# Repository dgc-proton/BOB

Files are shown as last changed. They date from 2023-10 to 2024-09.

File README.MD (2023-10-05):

#B.O.B. - Barely Operational Bot

Code - Robot Code
Model - CAD model
Design - Design/Idea files

## Git Guidelines

- don’t force any command without approval of everyone else
- don’t use advanced features that mess with file histories (though amend is ok when used properly)
- give descriptive commit messages
- keep commits small & often when possible (or when we remember!)
- use branches & merge changes form origin/main into the branch regularly

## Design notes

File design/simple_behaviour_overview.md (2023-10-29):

# B.O.B. Behaviour Overview

```mermaid
stateDiagram-v2

    state "Startup Health Check" as health_check
    state "Check for Opponent" as check
    state "Turn Towards Opponent\n(sensor distance min.)" as attack
    state "Check for Lines" as line_detect
    state "Steer Away from Line(s)" as line_avoid
    state "Maximum Power to Motors!" as steer_power
    state "Low Power to Motors" as go_slow
    state "Turn in One Direction" as turn_to_find

    [*] --> health_check: Power On
    health_check --> line_detect: Button Pressed
    line_detect --> check: No Line Detected
    line_detect --> line_avoid: Line Detected
    line_avoid --> line_detect
    check --> attack: Opponent Detected
    attack --> steer_power
    steer_power --> line_detect
    check --> go_slow: No Opponent Detected
    go_slow --> turn_to_find
    turn_to_find --> line_detect
```

# Navigation

### Inputs

* line sensors (IR x 2)
* object sensors (ultrasonic x 4)

### Map

Not used in the simple behaviour model.

### Path

Not used in the simple behaviour model.

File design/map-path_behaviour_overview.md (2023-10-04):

# B.O.B. Behaviour Overview

```mermaid
stateDiagram-v2

    state "Startup Health Check" as health_check
    note left of line_detect: An alternative would be to\nuse an Interupt Service\nRoutine for line detection
    state "Check for Opponent" as check
    state "Update Map & Path:\nDrive at Opponent /\nSearch Pattern" as attack
    state "Check for Lines" as line_detect
    state "Update Map & Path:\nAvoid Line (top priority)" as line_avoid
    state "Update Steering &\nAdjust Motor Power" as steering
    state "Update Steering &\nAdjust Motor Power" as steer_power

    [*] --> health_check: Power On
    health_check --> line_detect: Button Pressed
    line_detect --> check: No Line
    line_detect --> line_avoid: Line Detected
    line_avoid --> steering
    steering --> check
    check --> attack
    attack --> steer_power
    steer_power --> line_detect
```

# Navigation

### Inputs

* wheel encoders using ISR
* line sensors (IR x 4)
* object sensors (ultrasonic x ?)

### Map

Array that tracks the location of the bot, opponent (or last known location of opponent) and lines. As time passes localization gets less accurate, so should we remove or de-value data as it gets older? The location of the bot can be tracked by array indices giving the cell that the centre of the robot is in, and a unit vector for the direction it is facing.

Information on where the various sensors are (for object and line detection) located in relation to the centre of the bot will be needed to accurately update the map with the location of lines & opponent distance.

### Path

Algorithm that decides which way the bot should be facing and the speed that it should be going at, based on avoiding lines (highest priority) and finding or attacking the opponent.

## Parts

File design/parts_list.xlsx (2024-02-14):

Parts | Quantity | Links | Cost | Mass (g) | Total Mass
Hailege ESP32 ESP-32S ESP-WROOM-32 | 1 | N.A. | Given | 10 | 10
HC-SR04 Ultrasonic Sensor | 2 | N.A. | Given | 9 | 18
Battery | 1 | N.A. | Given | 200 | 200
Motor driver L298N | 1 | N.A. | Given | 33 | 33
N20 DC GEARED MOTOR | 2 | N.A. | Given | 10 | 20
43MM N20 | 2 | N.A. | Given | 19 | 38
QTR-1A Infrared | 2 | N.A. | Given | 0.2 | 0.4
Mass of Shell | 1 | N.A. | Estimated | 139.03 | 139.03
 |  |  |  |  | 458.43 | Sum
 |  |  |  |  | 41.57 | Remainder

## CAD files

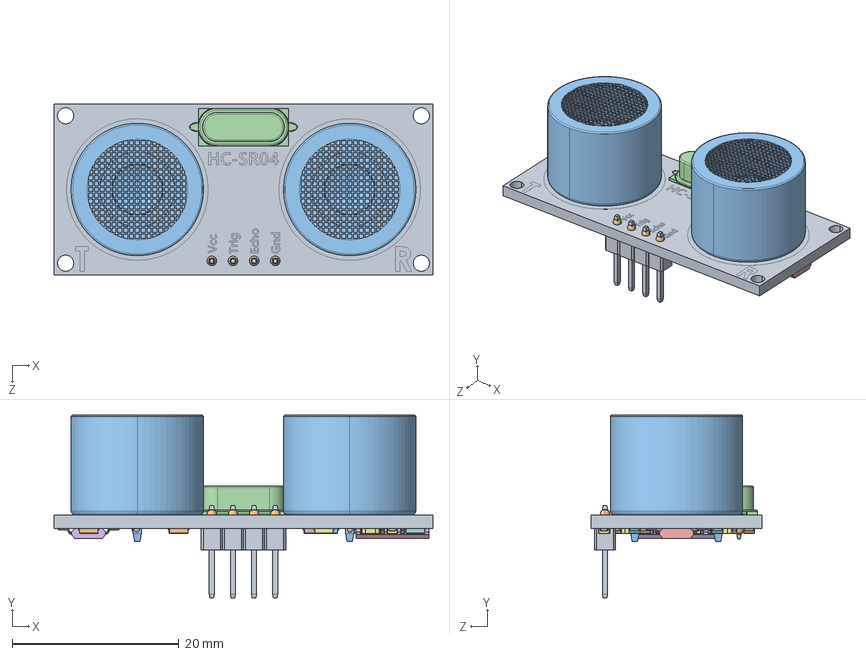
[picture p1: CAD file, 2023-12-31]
model/components/HC-SR04.SLDASM
45.5 x 22.0 x 20.5 mm
HC-SR04board.STEP
solder.STEP x 10
Emitter.STEP x 2
CrystalOscillator.STEP
smdChip14pin.STEP x 2
smdChip16pin.STEP
smdceramiccapacitor.STEP x 7
smdResistor753.STEP x 3
smdResistor392.STEP
smdResistor103.STEP x 6
smdResistor124.STEP x 2
smdResistor335.STEP
smdResistor102.STEP
smdResistor563.STEP
smdResistor622.STEP
smdResistor412.STEP
headerMale.STEP x 4

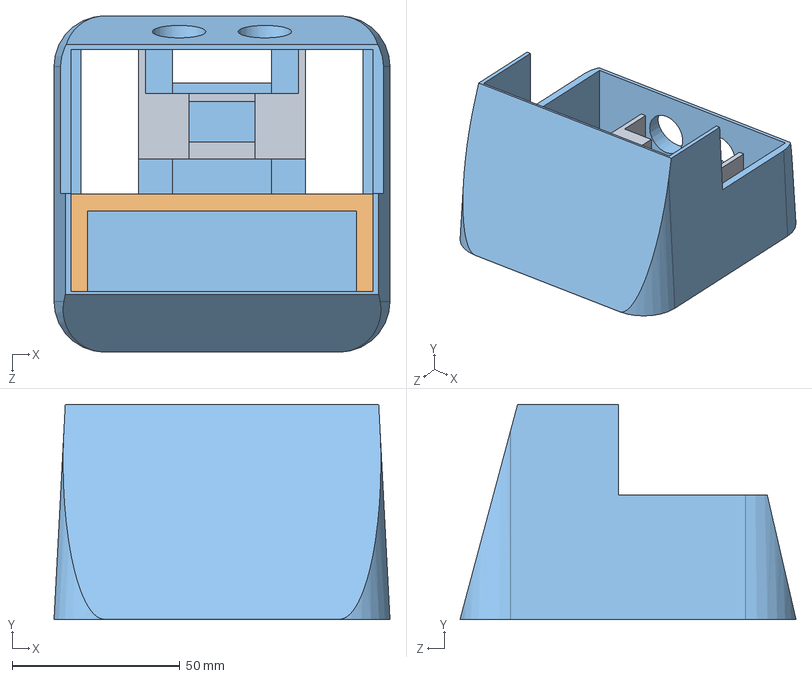
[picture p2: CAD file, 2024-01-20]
model/shell subparts/shell_assembly_test.SLDASM
100.0 x 64.0 x 100.0 mm
shell-part1
shell-part2
shell-part3

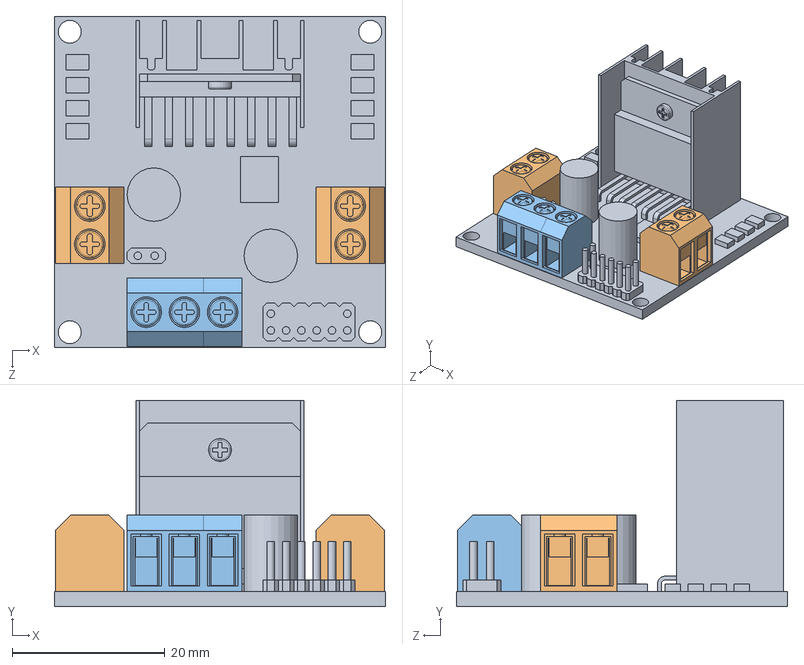
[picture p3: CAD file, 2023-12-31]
model/components/L298N.SLDASM
43.3 x 27.0 x 43.3 mm
Pcb
Pengunci x 2
Pengunci 2

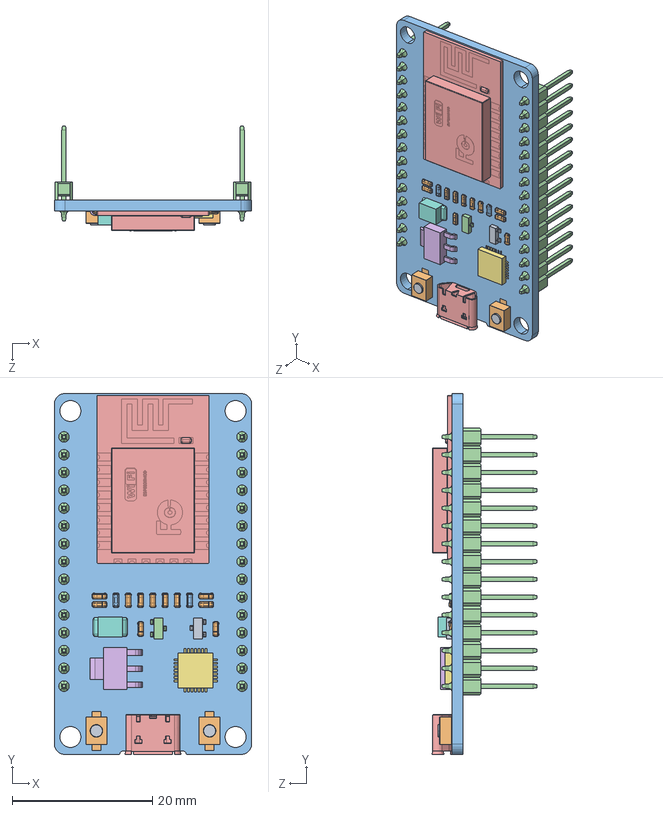
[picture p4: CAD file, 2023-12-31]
model/components/esp32_dev_kit_v1_asm.SLDASM
28.1 x 51.5 x 15.0 mm
BUTTONFLASH-13_2.stp x 2
BUTTONFLASH-14_2.stp x 2
PCB.stp
PIN.stp x 30
WIFI_CARD_2.stp
RECTANGULARCHIP_2.stp
MICROCHIP_2.stp
TANCHIP_2.stp
TRANSISTOR_3-LEG_2.stp
RESISTOR1_2.stp x 11
RESISTOR2-32_2.stp x 2
TRANSISTOR_3-LEG2_2.stp
USB_SOCKET_2.stp

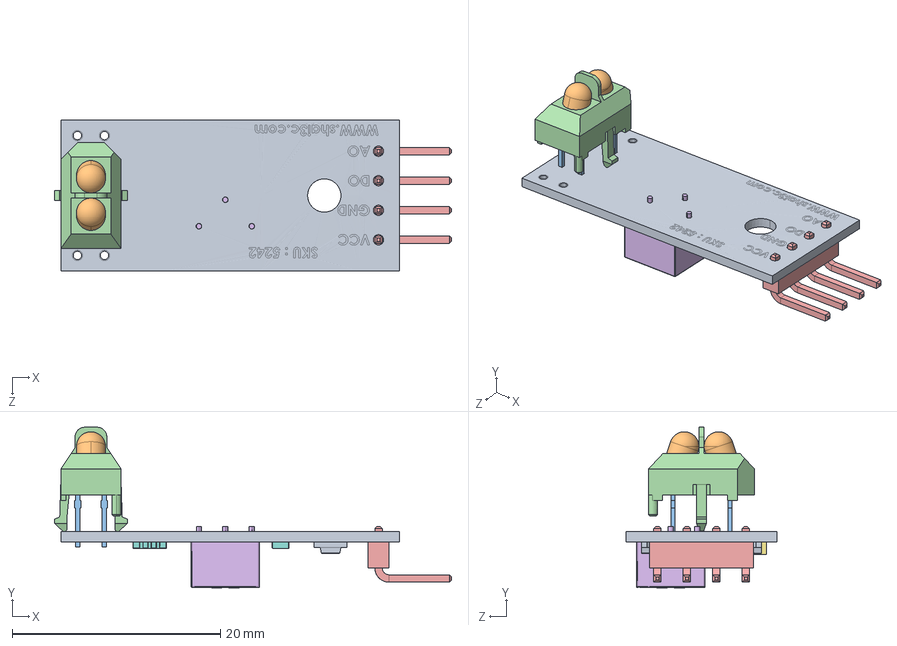
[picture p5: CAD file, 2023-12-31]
model/components/TCRT5000L Module.SLDASM
38.1 x 15.4 x 14.5 mm
Board.IGS
LEDs.IGS
Metal Contacts.IGS
TCRT50003.IGS
Pin Header.IGS
3362P-1-102LF-final.IGS
LM393 IC.IGS
103 SMD.IGS x 7
Surface Mount Chip LED 3.2x1.6mm 2.IGS x 2

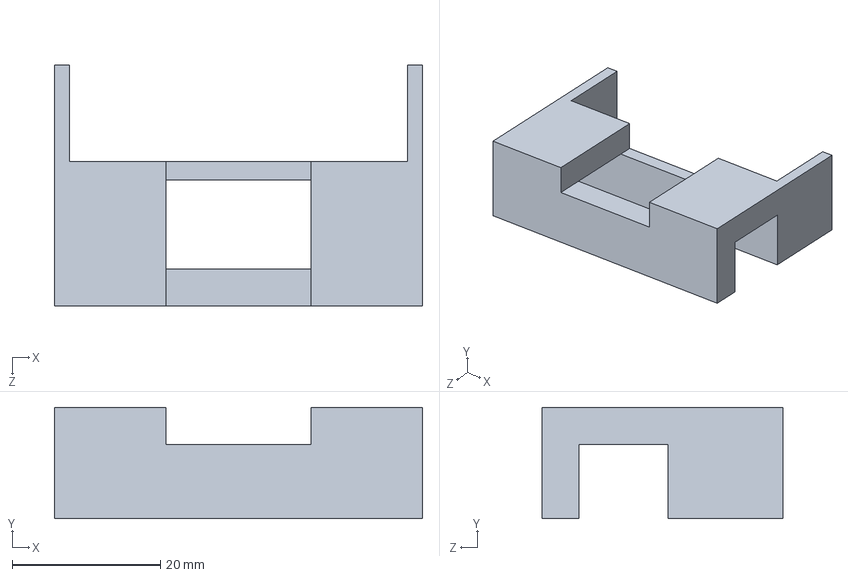
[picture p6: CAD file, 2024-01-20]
model/shell subparts/shell-part3.SLDPRT
49.6 x 15.0 x 32.5 mm

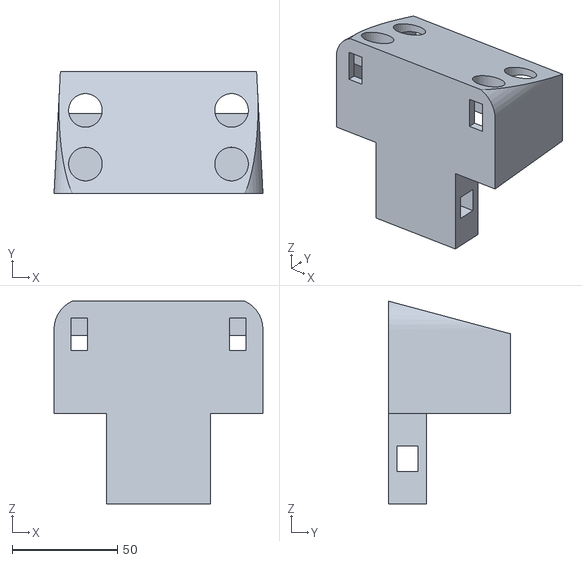
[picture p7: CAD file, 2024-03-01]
model/Shell-Print.STL
99.4 x 58.0 x 96.4

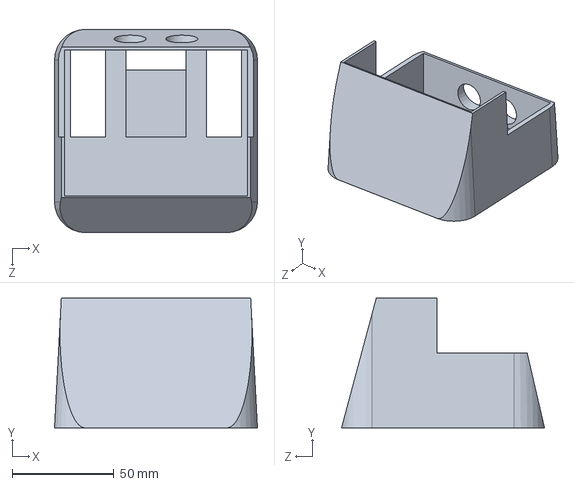
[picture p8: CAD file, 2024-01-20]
model/shell subparts/shell-part1.SLDPRT
100.0 x 64.0 x 100.0 mm

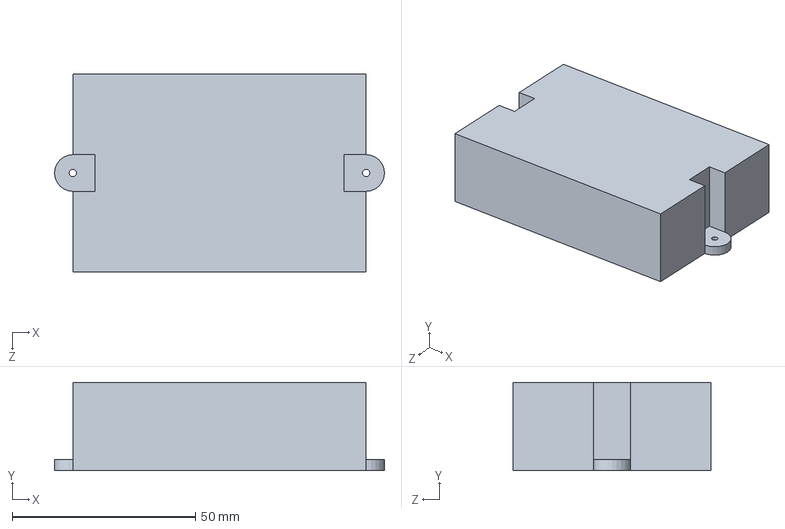
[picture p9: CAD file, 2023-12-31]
model/components/battery.SLDPRT
90.0 x 24.0 x 54.0 mm

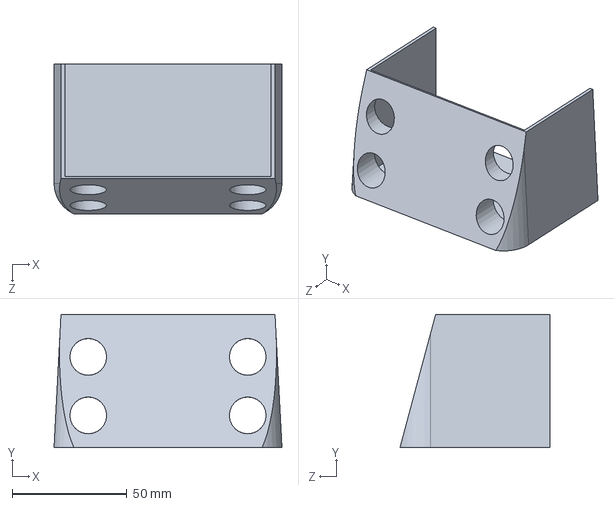
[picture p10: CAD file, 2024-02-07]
model/front.SLDPRT
99.4 x 58.0 x 65.4 mm

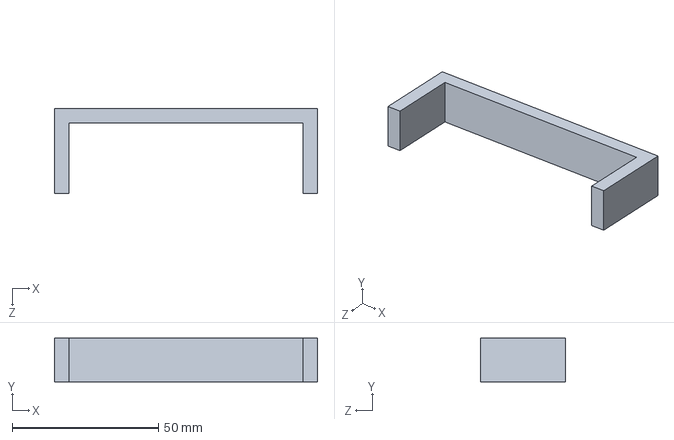
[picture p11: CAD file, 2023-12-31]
model/shell subparts/shell-part2.SLDPRT
90.0 x 15.0 x 29.0 mm

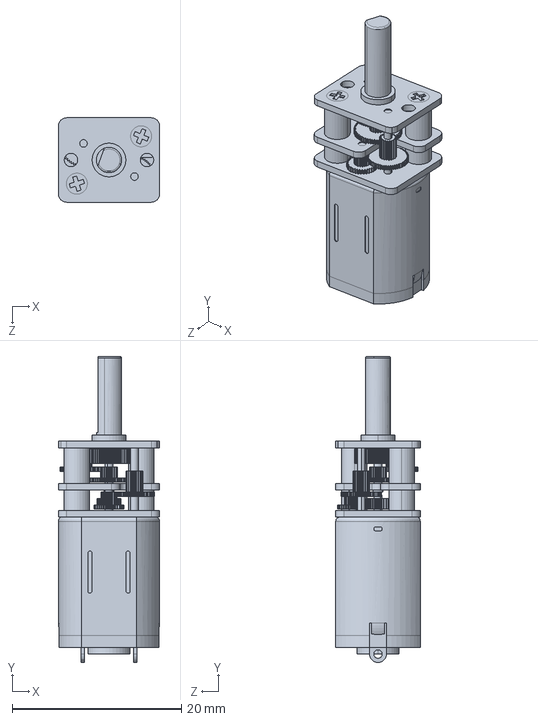
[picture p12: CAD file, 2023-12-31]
model/components/N20 DC MOTOR.step.SLDPRT
12.0 x 36.2 x 10.0 mm

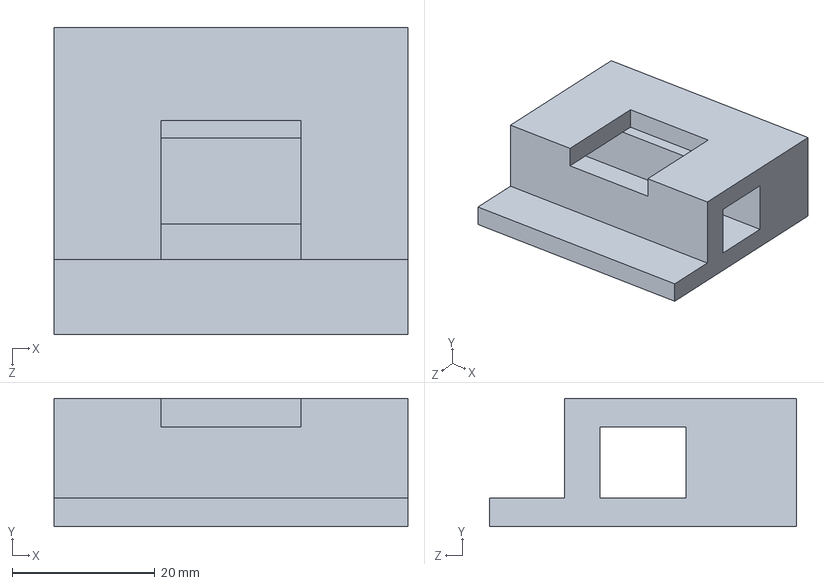
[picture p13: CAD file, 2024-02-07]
model/wheelbase.SLDPRT
49.6 x 18.0 x 43.0 mm

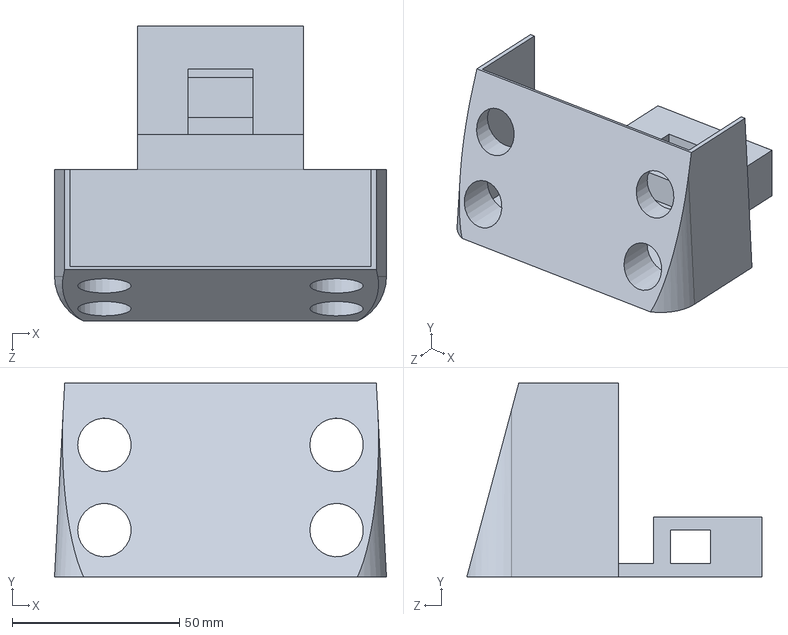
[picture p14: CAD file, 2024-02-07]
model/shell-bottomV3.SLDPRT
99.4 x 58.0 x 88.4 mm

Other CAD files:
model/components/QRE1113.SLDASM
model/BOB_assemblyV3.SLDASM
model/ShellV5.SLDPRT
model/components/Pengunci 2.SLDPRT
model/BOB_Assembly.SLDASM
model/Shell.SLDPRT
model/components/Pcb.SLDPRT
model/components/Pengunci.SLDPRT
model/components/QRE1113.SLDPRT
model/components/wheel.SLDPRT
model/old parts/BOB_assembly.SLDASM
model/old parts/BOB_assemblyV1.SLDASM
model/old parts/BOB_assemblyV2.SLDASM
model/old parts/Cut-Extrude2[1].SLDPRT
model/old parts/Cut-Extrude2[2].SLDPRT
model/old parts/Shell-assembly.SLDASM
model/old parts/sheelV4.SLDPRT
model/old parts/shell-bottom.SLDPRT
model/old parts/shell-bottomV2.SLDPRT
model/old parts/shell-topV2.SLDPRT
model/old parts/shell-topV3.SLDPRT
model/old parts/shell.SLDPRT
model/old parts/shellV2.SLDPRT
model/old parts/topV2_assembly.SLDASM
model/shell-bottom.SLDPRT
model/shell-bottomV2.SLDPRT
model/shell-top.SLDPRT
model/shell-topV2.SLDPRT
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

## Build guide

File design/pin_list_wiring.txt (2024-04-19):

Colour coding:
The bundle of four cables go diagonally across, so the ones sticking out the right are for the sensors on the left and vice-versa.
Red: 5V (apart from single wire from battery to H-Bridge which is 12V)
Black: ground (-ve battery terminal)
Yellow, bundle of 4: object sensors echo
Blue, bundle of 4: object sensors trigger
Green, bundle of 4: line sensors Vcc
White, bundle of 4: line sensors out
Bundle of 6, one of each colour: these are from the H-Bridge to the MCU so are fully visible

===================================================================================
FIXES REQUIRED
Common Pins:
GND H-Bridge: Ultrasonic Grounds, Line Sensor Grounds, Arduino Ground
5V H-Bridge: Ultrasonic Power, ESP32 VIN
Fixes:
Pin Soldering on Ultrasonics, Add ESP32 VIN to crimped connection

Battery Pins:
1. Power --> +12
2. Ground --> GND

H-Bridge
ENA --> 13
In1 --> 12
In2 --> 14

ENB --> 15
In3 --> 2
In4 --> 4

Line Sensors
Left Power --> 26
Left Out --> 27
Right Power --> 33
Right Out --> 25

Obj Sensors
Left Trigger --> 16
Left Echo --> 17
Right Trigger --> 5
Right Echo --> 18

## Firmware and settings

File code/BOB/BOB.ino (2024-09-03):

/*
**************************************
**  B.O.B. - Barely Operational Bot  **
**************************************
*
* Authors:
* Dave Riley
* Raghav Kejriwal
* Loïc Zammit
* 
* Code guidelines:
* 	- variable names should be all lowercase using underscores, struct or class names CamelCase, global variables prefixed with g_
* 	- use spaces around operators, apart from in arguments
* 	- first open brace { on same line, closing brace } a line by itself
* 	- keep things simple and readable
* 
* NB: With our board, may have to hold 'BOOT' Switch when uploading sketch
*
* ERROR CODES BUILTIN LED: (REPEAT ERROR CODES 10 TIMES IN 2 SEC INTERVALS (?))
* 1: . . . . . : Issue with update_motor, g_motor_commands has conflicting/erroneous values. Either turn is not within [-1, 1] or direction says reverse, but turn is not set to straight (0) {while this is possible to implement, it is rather confusing}. Hopefully code logic should never bring such a situation.
*/

/**********
Definitions
***********/

// left motor
#define LMOTOR_PWM_PIN   13
#define LMOTOR_DIR_PIN_1 12  // swapped the pin definitions around because motors were running in reverese
#define LMOTOR_DIR_PIN_2 14
const float LMOTOR_CORRECTION_FACTOR = 1; // must be <=1
const float LMOTOR_TURN_CORRECTION_FACTOR = 0.4; // motors slower in reverse

#if LMOTOR_CORRECTION_FACTOR > 1
	#error Motor correction factors must be less than or equal to 1
#endif

// right motor
#define RMOTOR_PWM_PIN   15
#define RMOTOR_DIR_PIN_2 32  // swapped the pin definitions around because motors were running in reverese
#define RMOTOR_DIR_PIN_1 4
const float RMOTOR_CORRECTION_FACTOR = 1; // must be <=1
const float RMOTOR_TURN_CORRECTION_FACTOR = 0.4; // motors slower in reverse

#if RMOTOR_CORRECTION_FACTOR > 1
	#error Motor correction factors must be less than or equal to 1
#endif

// both motors
#define MOTORMIN 60  // to account for deadband of motors, set based on motor with largest deadband
#define TURNING_FACTOR_FAST 50  // amount of PWM to decrease the turning wheel by when driving quickly

// IR line sensors
#define LINE_LEFT_PIN 27
#define LINE_LEFT_POWER_PIN 26
#define LINE_RIGHT_PIN 25
#define LINE_RIGHT_POWER_PIN 33
#define LINE_LEFT_THRESHOLD 1000  // based on manual callibration
#define LINE_RIGHT_THRESHOLD 1000  // based on manual callibration

//Object sensors
#define RING_SIZE 600

#define LOBJSENSOR_TRIG 16
#define LOBJSENSOR_ECHO 17

#define ROBJSENSOR_TRIG 5
#define ROBJSENSOR_ECHO 18

// Built-in LED
#define LED_BUILTIN 2

// START BUTTON
#define START_BUTTON 19

/***************
Global Variables
****************/

//Stores readings from the ultrasonic and infrared sensors
struct Sensors {
	float object_left = 4000.0;
	float object_right = 4000.0;
	float last_seen_right = true;
	bool line_left = false;
	bool line_right = false;
} g_sensor_readings;  // the structure name

// stores commands for motor power and steering
struct MotorCommands {
	int turn = 0; // -1 for left; 1 for right; 0 for straight.
	bool forward = true; // true for forward, false for reverse. Can only be in reverse if turn is set to 0, or straight! Not allowing a reverse turning possibility, since doing an on the spot turn anyways.
	int motor_power;
} g_motor_commands;  // the structure name

/******************
Function Prototypes
*******************/
void line_check(void);
void reverse_escape(void);
void single_side_escape(void);
void search_attack(void);
void update_object_sensors(void);
void update_motor(void);
void turn_left(void);
void turn_right(void);
void dir_forward(void);
void dir_reverse(void);

/*********
Setup Code
**********/
void setup() {
    Serial.begin(115200); //Starts serial output
    analogWrite(LMOTOR_PWM_PIN, 0);
    analogWrite(RMOTOR_PWM_PIN, 0);
	//Set built-in LED pin (D13) as output & switch on to show that setup in progress
	pinMode(LED_BUILTIN, OUTPUT);
	digitalWrite(LED_BUILTIN, HIGH);

	//Set motors pin modes
	pinMode(LMOTOR_DIR_PIN_1, OUTPUT);
	pinMode(LMOTOR_DIR_PIN_2, OUTPUT);
	pinMode(LMOTOR_PWM_PIN, OUTPUT); 
	pinMode(RMOTOR_DIR_PIN_1, OUTPUT);
	pinMode(RMOTOR_DIR_PIN_2, OUTPUT);
	pinMode(RMOTOR_PWM_PIN, OUTPUT);
	
	//Set ultrasonic sensor pin modes
	pinMode(LOBJSENSOR_TRIG, OUTPUT);
	pinMode(LOBJSENSOR_ECHO, INPUT);
	pinMode(ROBJSENSOR_TRIG, OUTPUT);
	pinMode(ROBJSENSOR_ECHO, INPUT);

	//Set line sensors pin mode
	pinMode(LINE_LEFT_POWER_PIN, OUTPUT);
	pinMode(LINE_RIGHT_POWER_PIN, OUTPUT);
	pinMode(LINE_LEFT_PIN, INPUT);
	pinMode(LINE_RIGHT_PIN, INPUT);

    // Start Button
    pinMode(START_BUTTON, INPUT_PULLUP);

	//Power on to the line sensors
	digitalWrite(LINE_LEFT_POWER_PIN, HIGH);
	digitalWrite(LINE_RIGHT_POWER_PIN, HIGH);

	//Set motors in forward direction
	dir_forward();

    for (int i=0; i<5; i++) {
        update_object_sensors();
    }

	//Blinks LED to show setup completed sucessfully
	for(int i=0; i<3; i++) {
		digitalWrite(LED_BUILTIN, LOW);
		delay(500);
		digitalWrite(LED_BUILTIN, HIGH);
		delay(500);
		digitalWrite(LED_BUILTIN, LOW);
	}

    while(true) {
        bool start_check = digitalRead(START_BUTTON);
        if (start_check == false) {
            break;
        }
    }

    g_motor_commands.motor_power = 80;
    update_motor();
    delay(400);
    g_motor_commands.motor_power = 0;
    update_motor();
}


/********
Main Code
*********/

void loop() { //Main Control loop	
	line_check(); //Checks for lines
    //update_object_sensors(); //debugging
	 //Bound detection
	if(g_sensor_readings.line_left && g_sensor_readings.line_right) {
    //If both lines detected in the front, reverse	
        //Serial.println("Reverse Escape");
		reverse_escape();
	} else if(g_sensor_readings.line_left) {
    //If one line detected in the left, turn right
        //Serial.println("Turning Right");
        left_side_escape();
	} else if(g_sensor_readings.line_right) {
    //If one line detected on the right, turn left
        //Serial.println("Turning Left");
        right_side_escape();
	} else {
    //If no bounds detected, search for opponent
		update_object_sensors();
        //Serial.println("Search Attack");
		search_attack();
	}

  // debugging
  
  /*Serial.print("object left: ");
  Serial.println(g_sensor_readings.object_left);
  Serial.print("object right: ");
  Serial.println(g_sensor_readings.object_right);
  Serial.print("last seen right?: ");
  Serial.println(g_sensor_readings.last_seen_right);
  Serial.print("line left: ");
  Serial.println(g_sensor_readings.line_left);
  Serial.print("line right: ");
  Serial.println(g_sensor_readings.line_right);
  Serial.print("turn (-1 left, 0 straight, 1 right): ");
  Serial.println(g_motor_commands.turn);
  Serial.print("forward? ");
  Serial.println(g_motor_commands.forward);
  Serial.print("motor power: ");
  Serial.println(g_motor_commands.motor_power);
  Serial.println();
  delay(5000);*/
  
}


void line_check() { 
    //Update values for lines sensed from the QRE1113 **DIGITAL** breakout board sensors 
  //Lower numbers mean more refleacive, more than 3000 means nothing was reflected
  //(testing on black tape and white masking tape suggest anything below 150 is a white line)
  if (min(g_sensor_readings.object_left,g_sensor_readings.object_right) < 100) {
    return;
  }
  pinMode(LINE_LEFT_PIN, OUTPUT);
  digitalWrite(LINE_LEFT_PIN, HIGH);  
  delayMicroseconds(10);
  pinMode(LINE_LEFT_PIN, INPUT);
  long time = micros();
  //time how long the input is HIGH, but quit after 3ms as nothing happens after that
  while (digitalRead(LINE_LEFT_PIN) == HIGH && micros() - time < 3000);
  int diff = micros() - time;
  Serial.print("Left:");
  Serial.println(diff);
	if(diff < LINE_LEFT_THRESHOLD){
		g_sensor_readings.line_left = true;
	} else {
		g_sensor_readings.line_left = false;
	}

  pinMode(LINE_RIGHT_PIN, OUTPUT);
  digitalWrite(LINE_RIGHT_PIN, HIGH);  
  delayMicroseconds(10);
  pinMode(LINE_RIGHT_PIN, INPUT);
  time = micros();
  //time how long the input is HIGH, but quit after 3ms as nothing happens after that
  while (digitalRead(LINE_RIGHT_PIN) == HIGH && micros() - time < 3000);
  diff = micros() - time;
  Serial.print("Right:");
  Serial.println(diff);
	if(diff < LINE_RIGHT_THRESHOLD){
		g_sensor_readings.line_right = true;
	} else {
	        g_sensor_readings.line_left = false;
        }
}

void update_object_sensors() {
	// Updates the global struct with readings from the object sensors. If sight of
	// the enemy is lost, also updates the history of direction enemy was last seen in

	// Ultrasonics output HIGH pulse for the amount of time it takes the waves to reflect back
	// pulseIn measures that, and distance in mm is then calculated
	
	//Left utrasonic sensor
    digitalWrite(LOBJSENSOR_TRIG, LOW);
	delayMicroseconds(2);
	digitalWrite(LOBJSENSOR_TRIG, HIGH);
	delayMicroseconds(10);
	digitalWrite(LOBJSENSOR_TRIG, LOW);
	int Lduration = pulseIn(LOBJSENSOR_ECHO, HIGH);
	
    //Right ultrasonic sensor
	digitalWrite(ROBJSENSOR_TRIG, LOW);
	delayMicroseconds(2);
	digitalWrite(ROBJSENSOR_TRIG, HIGH);
	delayMicroseconds(10);
	digitalWrite(ROBJSENSOR_TRIG, LOW);
	int Rduration = pulseIn(ROBJSENSOR_ECHO, HIGH);
	
	float Ldistance = Lduration * 0.34/2;
	float Rdistance = Rduration * 0.34/2;
	
	// Updates history of direction enemy was last seen in
	if(min(Ldistance, Rdistance) > RING_SIZE && min(g_sensor_readings.object_left, g_sensor_readings.object_right) < RING_SIZE) {
		float left_right = g_sensor_readings.object_left - g_sensor_readings.object_right;
		if(left_right >= 0) {
			g_sensor_readings.last_seen_right = true;
		} else if(left_right < 0) {
			g_sensor_readings.last_seen_right = false;
		}
	}
	g_sensor_readings.object_left = Ldistance;
	g_sensor_readings.object_right = Rdistance;

	return;
}

void reverse_escape() {
	// does a quick reverse, a turn, then returns control of motor and steering to normal
	// sets motors to reverse direction, delays to make sure it gets somewhere before checking for next loop iteration. completes a line check and iteration of loop done if line check still returns positive
	do {
		g_motor_commands.motor_power = 255;
		dir_reverse();
		// revers set to high speed so can counter forward momentum if needed.
		delay(500);
		line_check();
	} while(g_sensor_readings.line_left && g_sensor_readings.line_right);
	if(g_sensor_readings.last_seen_right == true) {
		g_motor_commands.motor_power = 60;
		turn_right();
	} else {
		g_motor_commands.motor_power = 60;
		turn_left();
	}
	delay(200);
	g_motor_commands.motor_power = 0;
	dir_forward();
	return;
}

void left_side_escape() {
    do {
		g_motor_commands.motor_power = 100;
		dir_reverse();
		// revers set to high speed so can counter forward momentum if needed.
		delay(150);
		line_check();
	} while(g_sensor_readings.line_left && g_sensor_readings.line_right);
    g_motor_commands.motor_power = 60;
    turn_right();
    delay(200);
    return;
}

void right_side_escape() {
    do {
		g_motor_commands.motor_power = 100;
		dir_reverse();
		// revers set to high speed so can counter forward momentum if needed.
		delay(150);
		line_check();
	} while(g_sensor_readings.line_left && g_sensor_readings.line_right);
    g_motor_commands.motor_power = 60;
    turn_left();
    delay(200);
    return;
}


void search_attack() {// Searches for the opponent, if opponent found to be in range will accelerate full speed at them

	if(min(g_sensor_readings.object_left, g_sensor_readings.object_right) > RING_SIZE){
		// the enemy is not in range, turn in the direction they were last seen
		if(g_sensor_readings.last_seen_right){
			g_motor_commands.motor_power = 60;
			turn_right();
            delay(200);
            g_motor_commands.motor_power = 0;
            dir_forward();
            //Serial.println("Stopped");
            //delay(1000);
			return;
		}else{
			g_motor_commands.motor_power = 60;
			turn_left();
            delay(200);
            g_motor_commands.motor_power = 0;
            dir_forward();
            //Serial.println("Stopped");
            //delay(1000);
			return;
		}
	}

	// If we haven't returned to the caller yet then the enemy is in range
	float left_minus_right = g_sensor_readings.object_left - g_sensor_readings.object_right;
	if(abs(left_minus_right) < 100){
		// If the enemy is pretty much in front of us, CHARGE!
		g_motor_commands.motor_power = 255;
		dir_forward();
		return;
	}

	// If we haven't charged then we need to turn to face the enemy better
	if(left_minus_right > 100){
		g_motor_commands.motor_power = 60;
		turn_right();
		return;
	} else {
		g_motor_commands.motor_power = 60;
		turn_left();
		return;
	}
}


void update_motor() {
	// logic to update output values to motor based on global variable values
	// Sets directions for both motors. true value means forward, false value means reverse
	int LMOTORPWR = 0;
	int RMOTORPWR = 0;

	if(g_motor_commands.turn == -1 && g_motor_commands.forward == true) {
        // Left Turn
		digitalWrite(LMOTOR_DIR_PIN_1, HIGH);
		digitalWrite(LMOTOR_DIR_PIN_2, LOW);
		digitalWrite(RMOTOR_DIR_PIN_1, LOW);
		digitalWrite(RMOTOR_DIR_PIN_2, HIGH);
		LMOTORPWR = g_motor_commands.motor_power * LMOTOR_CORRECTION_FACTOR * LMOTOR_TURN_CORRECTION_FACTOR;
		RMOTORPWR = g_motor_commands.motor_power * RMOTOR_CORRECTION_FACTOR * RMOTOR_TURN_CORRECTION_FACTOR;
	} else if(g_motor_commands.turn == 1 && g_motor_commands.forward == true) {
        // Right Turn
		digitalWrite(LMOTOR_DIR_PIN_1, LOW);
		digitalWrite(LMOTOR_DIR_PIN_2, HIGH);
		digitalWrite(RMOTOR_DIR_PIN_1, HIGH);
		digitalWrite(RMOTOR_DIR_PIN_2, LOW);
		LMOTORPWR = g_motor_commands.motor_power * LMOTOR_CORRECTION_FACTOR * LMOTOR_TURN_CORRECTION_FACTOR;
		RMOTORPWR = g_motor_commands.motor_power * RMOTOR_CORRECTION_FACTOR * RMOTOR_TURN_CORRECTION_FACTOR;
	} else if(g_motor_commands.turn == 0 && g_motor_commands.forward == true) {
        // Forwards
		digitalWrite(LMOTOR_DIR_PIN_1, LOW);
		digitalWrite(LMOTOR_DIR_PIN_2, HIGH);
		digitalWrite(RMOTOR_DIR_PIN_1, LOW);
		digitalWrite(RMOTOR_DIR_PIN_2, HIGH);
		LMOTORPWR = g_motor_commands.motor_power * LMOTOR_CORRECTION_FACTOR;
		RMOTORPWR = g_motor_commands.motor_power * RMOTOR_CORRECTION_FACTOR;
	} else if(g_motor_commands.turn == 0 && g_motor_commands.forward == false) {
        // Reverse
		digitalWrite(LMOTOR_DIR_PIN_1, HIGH);
		digitalWrite(LMOTOR_DIR_PIN_2, LOW);
		digitalWrite(RMOTOR_DIR_PIN_1, HIGH);
		digitalWrite(RMOTOR_DIR_PIN_2, LOW);
		LMOTORPWR = g_motor_commands.motor_power * LMOTOR_CORRECTION_FACTOR;// + MOTORMIN;
		RMOTORPWR = g_motor_commands.motor_power * RMOTOR_CORRECTION_FACTOR;// + MOTORMIN;
	}
	// ERROR CODE 1
	else {
		for (int j = 0; j < 10; j++) {
			for (int i = 0; i < 5; i++) {
				digitalWrite(LED_BUILTIN, LOW);
				delay (500);
				digitalWrite(LED_BUILTIN, HIGH);
				delay(500);
				digitalWrite(LED_BUILTIN, LOW);
			}
			delay(2000);
		}
	}
    
    if (LMOTORPWR != 0 && RMOTORPWR !=0 && max(LMOTORPWR, RMOTORPWR) < 255 - MOTORMIN) {
        LMOTORPWR = LMOTORPWR + MOTORMIN;
        RMOTORPWR = RMOTORPWR + MOTORMIN;
    }
	
    analogWrite(LMOTOR_PWM_PIN, LMOTORPWR);
    analogWrite(RMOTOR_PWM_PIN, RMOTORPWR);
	
    return;
}

void turn_left() {
	g_motor_commands.turn = -1;
	g_motor_commands.forward = true;
	update_motor();
}

void turn_right() {
	g_motor_commands.turn = 1;
	g_motor_commands.forward = true;
	update_motor();
}

void dir_forward() {
	g_motor_commands.turn = 0;
	g_motor_commands.forward = true;
	update_motor();
}

void dir_reverse() {
	g_motor_commands.turn = 0;
	g_motor_commands.forward = false;
	update_motor();
}

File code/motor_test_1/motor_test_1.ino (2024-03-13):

#define LMOTOR_PWM_PIN 13
#define LMOTOR_DIR_PIN_1 14
#define LMOTOR_DIR_PIN_2 12
#define LMOTOR_CORRECTION_FACTOR 1

#define RMOTOR_PWM_PIN 15
#define RMOTOR_DIR_PIN_1 2
#define RMOTOR_DIR_PIN_2 4
#define RMOTOR_CORRECTION_FACTOR 1

#define DELAY_TIME 5000

int motorPower;
bool rmotor_dir;
bool lmotor_dir;

void direction_change() {
	if(rmotor_dir) {
		digitalWrite(RMOTOR_DIR_PIN_1, LOW);
		digitalWrite(RMOTOR_DIR_PIN_2, HIGH);
	}
	else {
		digitalWrite(RMOTOR_DIR_PIN_1, HIGH);
		digitalWrite(RMOTOR_DIR_PIN_2, LOW);
	}
	if(lmotor_dir) {
		digitalWrite(LMOTOR_DIR_PIN_1, LOW);
		digitalWrite(LMOTOR_DIR_PIN_2, HIGH);
	}
	else {
		digitalWrite(LMOTOR_DIR_PIN_1, HIGH);
		digitalWrite(LMOTOR_DIR_PIN_2, LOW);
	}
}

void turn_right() {
	rmotor_dir = false;
	lmotor_dir = true;
	direction_change();
}

void turn_left() {
	rmotor_dir = true;
	lmotor_dir = false;
	direction_change();
}

void setup() {
	Serial.begin(115200);
	//Motor Output Pins
	pinMode (LMOTOR_DIR_PIN_1, OUTPUT);
	pinMode (LMOTOR_DIR_PIN_2, OUTPUT);
	pinMode (LMOTOR_PWM_PIN, OUTPUT);
	pinMode (RMOTOR_DIR_PIN_1, OUTPUT);
	pinMode (RMOTOR_DIR_PIN_2, OUTPUT);
	pinMode (RMOTOR_PWM_PIN, OUTPUT);
	//Motor Direction Forwards
	digitalWrite (LMOTOR_DIR_PIN_1, LOW);
	digitalWrite (LMOTOR_DIR_PIN_2, HIGH);
	digitalWrite (RMOTOR_DIR_PIN_1, LOW);
	digitalWrite (RMOTOR_DIR_PIN_2, HIGH);
	
}

void loop(){
  digitalWrite (LMOTOR_DIR_PIN_1, LOW);
	digitalWrite (LMOTOR_DIR_PIN_2, HIGH);
	digitalWrite (RMOTOR_DIR_PIN_1, LOW);
	digitalWrite (RMOTOR_DIR_PIN_2, HIGH);
	//High Speed LMotor Forwards
  Serial.println("High Speed LMotor Forwards");
	motorPower = 255;
	analogWrite (LMOTOR_PWM_PIN, motorPower);
	delay (DELAY_TIME);
	//Low Speed LMotor Forwards
  Serial.println("Low Speed LMotor Forwards");
	motorPower = 50;
	analogWrite (LMOTOR_PWM_PIN, motorPower);
	delay (DELAY_TIME);
	//Stop LMotor
  Serial.println("Stop LMotor");
	motorPower = 0;
	analogWrite (LMOTOR_PWM_PIN, motorPower);
	delay(DELAY_TIME);
	
	//High Speed RMotor Forwards
  Serial.println("High Speed RMotor Forwards");
	motorPower = 255;
	analogWrite (RMOTOR_PWM_PIN, motorPower);
	delay (DELAY_TIME);
	//Low Speed RMotor Forwards
  Serial.println("Low Speed RMotor Forwards");
	motorPower = 50;
	analogWrite (RMOTOR_PWM_PIN, motorPower);
	delay (DELAY_TIME);
	//Stop RMotor
  Serial.println("Stop RMotor");
	motorPower = 0;
	analogWrite (RMOTOR_PWM_PIN, motorPower);
	delay(DELAY_TIME);
	
	//Reverse Directions
	digitalWrite (LMOTOR_DIR_PIN_1, HIGH);
	digitalWrite (LMOTOR_DIR_PIN_2, LOW);
	digitalWrite (RMOTOR_DIR_PIN_1, HIGH);
	digitalWrite (RMOTOR_DIR_PIN_2, LOW);
	
	//Same routine as forwards
  Serial.println("High Speed LMotor Backwards");
	motorPower = 255;
	analogWrite (LMOTOR_PWM_PIN, motorPower);
	delay (DELAY_TIME);
  Serial.println("Low Speed LMotor Backwards");
	motorPower = 50;
	analogWrite (LMOTOR_PWM_PIN, motorPower);
	delay (DELAY_TIME);
  Serial.println("Stop LMotor");
	motorPower = 0;
	analogWrite (LMOTOR_PWM_PIN, motorPower);
	delay(DELAY_TIME);
	
  Serial.println("High Speed RMotor Backwards");
	motorPower = 255;
	analogWrite (RMOTOR_PWM_PIN, motorPower);
	delay (DELAY_TIME);
  Serial.println("Low Speed RMotor Backwards");
	motorPower = 50;
	analogWrite (RMOTOR_PWM_PIN, motorPower);
	delay (DELAY_TIME);
  Serial.println("Stop RMotor");
	motorPower = 0;
	analogWrite (RMOTOR_PWM_PIN, motorPower);
	delay(DELAY_TIME);
	
  Serial.println("Turn Right Routine");
	turn_right();

  Serial.println("Stop Both Motor");
	motorPower = 0;
	analogWrite (LMOTOR_PWM_PIN, motorPower);
  analogWrite (RMOTOR_PWM_PIN, motorPower);

  Serial.println("Set L & R Motors to Max");
	motorPower = 255;
	analogWrite (LMOTOR_PWM_PIN, motorPower);
	
	motorPower = 255;
	analogWrite (RMOTOR_PWM_PIN, motorPower);
	
	delay(DELAY_TIME);
	
  Serial.println("Stop Both Motor");
	motorPower = 0;
	analogWrite (LMOTOR_PWM_PIN, motorPower);
  analogWrite (RMOTOR_PWM_PIN, motorPower);

	Serial.println("Turn Left Routine");
	turn_left();

  Serial.println("Set L & R Motors to Max");
	motorPower = 255;
	analogWrite (LMOTOR_PWM_PIN, motorPower);
	
	motorPower = 255;
	analogWrite (RMOTOR_PWM_PIN, motorPower);
	
	delay(DELAY_TIME);

  Serial.println("Stop Both Motors");
  motorPower = 0;
  analogWrite (RMOTOR_PWM_PIN, motorPower);
  analogWrite (LMOTOR_PWM_PIN, motorPower);

  delay(DELAY_TIME);

}

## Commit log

2023-10-04 Updated behaviour overview
    Added details about mapping including that sensor locations to be accounted for
2023-10-04 Basic unfinished shell and BOB assembly added
    [BOB Assembly.SLDASM, Shell.SLDPRT]
2023-10-04 Removed placeholder and useless gitignore file + updated assembly and added component
    [BOB Assembly.SLDASM, BOB_Assembly.SLDASM, arduino_uno.SLDPRT]
2023-10-05 Added part_lists excel file and ultrasonic sensor CAD model
    [HC-SR04.SLDASM, parts_list.xlsx]
2023-10-05 Added new parts and their mass to parts_list + added new models for components
    [L298N.SLDASM, N20 DC MOTOR.step.SLDPRT, Pcb.SLDPRT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]
2023-10-07 Added battery footprint part (still needs dimensioning) and setup basic arduino files for coding later
    [battery.SLDPRT]
2023-10-11 Changed design behaviour files
    Changed name of behaviour_overview to map-path_behaviour_overview; this is the more complex idea, and will not be developed at the moment. Created simple_behaviour_overview, which is the current work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
2023-10-11 Modeled battery
    [battery.SLDPRT]
2023-10-11 Defining basic Functions
    Added in basic function definitions to get an idea of how we want it to switch between functions and what function parameters are required
2023-10-12 Updated simple behaviour code
    Added some general #macros, structs and further developed the code & pseudocode that had already been written. Also added a draft calibration routing for IR sensor that we can test and modify when th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
2023-10-29 Changed number of ultrasonic sensors in overview.md
2023-11-01 Fixing automatic tab and indentation issues
    [BOB.ino]
2023-11-01 Motor Subroutine File
    Added motor subroutine file to test the motor and the new board
2023-11-08 Added in NB in title block
    With the board we have, physical BOOT button must be held down to upload sketch from IDE. Added reminder in the title block just in case.
2023-11-08 Updated parts list, components, shell and assembly
    [BOB_Assembly.SLDASM, arduino_uno.SLDPRT, esp32_dev_kit_v1_asm.SLDASM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]
2023-11-15 Worked on Reverse Escape Function
    Reverse Escape is ready. Changes to be made can only be made once its built and tested. Feature currently does one iteration of loop wherein it reverses, before doing a line check and only does next iteration if lines are still seen.
    It then does a slow right hand turn, and control goes back to loop(). Commented Out code has do while loop for this part, not sure if needed, might use in case of bugs
    [BOB.ino]
2023-11-15 Changed Motor Subroutine File
    Changed Motor Subroutine File to test turns, and added in different variables and functions for turning left or right. Testing it out before we make large changes to main code. Thinking of changing v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
2023-11-22 moved motor test routine
    moved motor test routine to own folder with correct Arduino IDE structure
2023-11-22 corrected part of move of motor test routine file
    [motor_test_1.ino]
2023-11-22 change motor test file delays, fixed bug with motor not stopping
    [motor_test_1.ino]
2023-11-22 created a basic motor pin testing sketch
2023-11-29 Motor Test
    File updated, changes to routine slightly to make things easier to understand. There is a difference in speeds, but can correct that in the future once wheels are added on
    [motor_test_1.ino]
2023-11-29 Updated pin definitions
2023-11-30 update_motor implemented after motor test was successful + changes to global variables + added error codes.
    1. g_motor_commands no longer has turn_left and turn_right, but rather int turn and bool forward.
    2. Functions added turn_left, turn_right, dir_forward, dir_reverse. These were added to make one line direction changes. These call update_motor() themselves.
    3. Added led error code for update_motor() for conflicting values that can be used but make it more complex for no reason. ERROR CODES section added in title block.
    [BOB.ino]
2023-11-30 Defined Error Code 1 Properly
    Had forgotten to define error code 1 in title block previously and what it means
    [BOB.ino]
2023-12-20 Fixing minor logic in update_motor()
    [BOB.ino]
2023-12-31 Finished work on CAD model
    [BOB_assemblyV2.SLDASM, HC-SR04.SLDASM, L298N.SLDASM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]
2024-01-20 Updated BOB model - Moved IR sensors forward and added connection points for the two shell halves
    [BOB_Assembly.SLDASM, BOB_assembly.SLDASM, BOB_assemblyV2.SLDASM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]
2024-02-07 Fixed a few bits off redundant code
    [BOB.ino]
2024-02-07 removed Single Side escape function when I realised its no longer needed
    [BOB.ino]
2024-02-07 Version 2 of BOB Model
    [BOB_assemblyV1.SLDASM, BOB_assemblyV2.SLDASM, parts_list.xlsx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]
2024-02-07 Final BOB Design
    [BOB_assemblyV2.SLDASM, BOB_assemblyV3.SLDASM, QRE1113.SLDASM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]
2024-02-14 Updated code (mainly search_attack function) to allow for two front facing object sensors, also added history to global struct for where enemy last seen. Function to update object sensor readings sti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
2024-02-14 Final model revision before print
    [BOB_assemblyV3.SLDASM, Cut-Extrude2[1].SLDPRT, Cut-Extrude2[2].SLDPRT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]
2024-02-21 Added the code for the function to update object sensors. Also added a test file for the same.
2024-02-21 Changed some erroneous code with the object sensor updating
2024-02-21 Added pins instead of placeholders. Nothing set in stone though, will probably change based on easier wirings, but this is just for testing.
2024-03-01 Small code readability fixes
    [Shell-Print.STL]
2024-03-13 Preliminary testing, changed some code, added pin nmbers, turn correction factors, fixed some bugs
    [BOB.ino, motor_test_1.ino]
2024-03-27 Added Text File containing wiring descriptions and fixes RE bug report
2024-04-17 Added a Wiring List with some required fixes
2024-04-18 changed how line sensors are read, fixed minor issues with motor control
    Now BOB has reliable wiring bugs are a lot easier to track down. Added (and commented out) some debugging code which prints global struct values over serial connection. The previous version of the line sensor code was written for breakout boards which have only resistors on the phototransistor collector; the breakout boards we are using have a cap so need different code to read without weird bugs / errors.
    [BOB.ino]
2024-04-18 added schematic for the version of IR sensor breakout board which we are using, note it has a cap
2024-04-19 corrected some formatting for the wiring / pin-out document
2024-04-22 General Debugging. Swapped pins, added debug lines. search_attack now does a stepped turn rather than continuous. Changed Object Sensor Difference Threshold.
    [BOB.ino]
2024-04-23 fixed some pin definitions in simple_BOB
    [simple_BOB.ino]
2024-04-23 Changed Reverse Escape once again for bug fixes/performance.
    [BOB.ino]
2024-04-23 Bugs and behaviour changes after testing on the actual ring. Fine tuned delays, speeds, added single side line escapes.
    [BOB.ino]
2024-04-23 More bug fixes post testing, added a timing check so line sensors dont take false values in case they are past the line slightly (**This still requires some testing**).
    [BOB.ino]
2024-04-24 Behaviour Changes, saving fo rlater. Will be reverting back to previous commit due to bug
    [BOB.ino]
2024-05-23 Changes to code for competition, reverted back to old version with some changes to behaviour constants, speeds, delays due to issues on new feature implementation.
    [BOB.ino]
